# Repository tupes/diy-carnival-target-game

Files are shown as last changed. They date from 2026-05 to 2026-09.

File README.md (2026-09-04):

# DIY Electromechanical Carnival Target Game

> A one-off electromechanical arcade game independently engineered and fabricated as a gift—from embedded firmware and electronics to parametric CAD, 3D-printed mechanisms, and a full wooden cabinet.

<p align="center">
  <a href="docs/media/diy-carnival-target-gameplay.mp4">
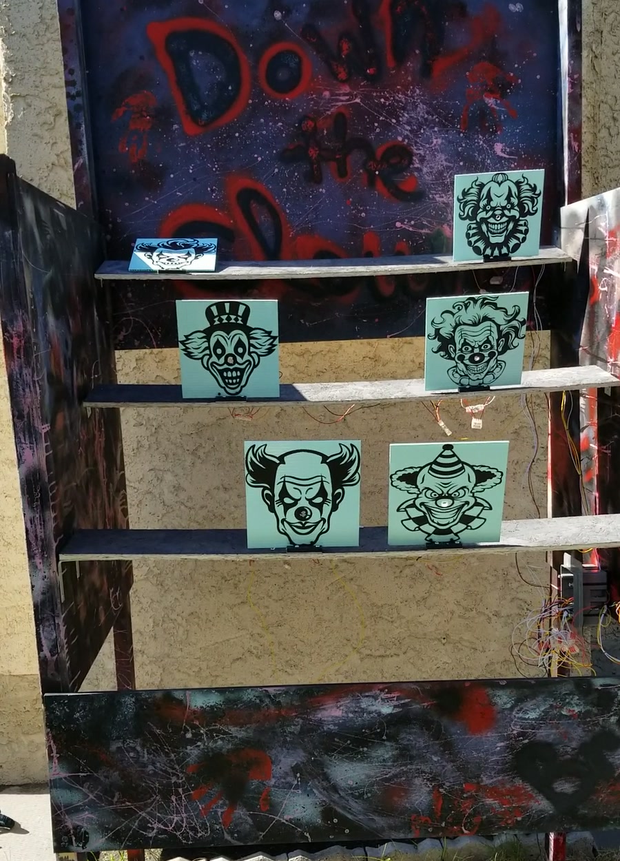
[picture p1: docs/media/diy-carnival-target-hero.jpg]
Completed wooden DIY electromechanical carnival target game
    
  </a>
</p>
<p align="center"><em>Completed integrated build during a live play session. Select the image to watch the full demonstration.</em></p>

The game turns a carnival ball toss into a 30-second embedded challenge. A player taps the M5Stack touchscreen to start, then throws balls at color-coded hinged clown targets. Each hit is detected by an ESP32, scored according to the target's current difficulty, acknowledged with sound and an updated display, and followed by an automatic servo-driven reset.

This project is an end-to-end build: interaction design, game logic, wireless communication, sensor and actuator integration, parametric mechanical design, fabrication, cabinet construction, system debugging, and delivery of a finished physical product.

The direct inspiration was [ICE's *Down the Clown* arcade game](https://www.icegame.com/games/down-the-clown/), which I enjoy playing. I recreated the experience as a non-commercial learning project, designing and implementing the firmware, electronics, mechanisms, CAD, fabrication workflow, and cabinet independently.

> [!IMPORTANT]
> This independent fan project is not affiliated with or endorsed by Innovative Concepts in Entertainment, Inc. No ICE software, artwork, audio, mechanical drawings, or fabrication files are included. Historical media shows the original working title used on the completed gift; that name is referenced here only to identify the inspiration.

## Engineering scope

| Area | Work delivered |
| --- | --- |
| Embedded systems | Wrote MicroPython firmware for an ESP32 target controller and an M5Stack touchscreen interface |
| Electronics | Integrated active-low hit switches, PWM-controlled servos, clocked addressable RGB lights, and embedded audio |
| Communication | Split real-time responsibilities across two controllers using routerless ESP-NOW broadcasts |
| Mechanical design | Created parametric servo cams, brackets, switch mounts, hinge stops, and a cabinet layout in Python |
| Fabrication | Produced vendor-neutral STEP exports and slicer-ready 3MF files, iterated on fit and geometry, and built the wooden cabinet |
| Integration and delivery | Brought firmware, wiring, printed parts, moving targets, UI, and enclosure together as a playable gift |

## Gameplay demonstration

<p align="center">
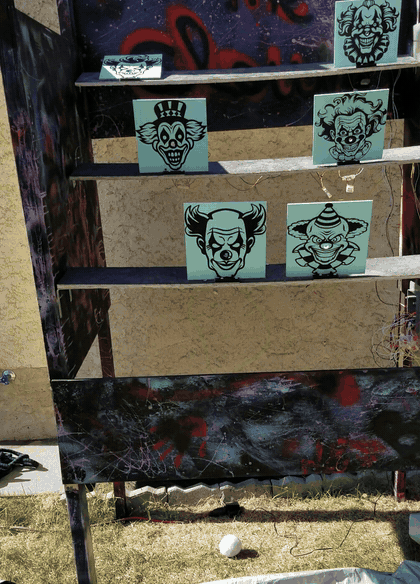
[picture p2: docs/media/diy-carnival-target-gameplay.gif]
A ball knocks down a clown target before the servo and cam automatically raise it
  
</p>

*A successful hit followed by the two-second cooldown and servo/cam reset.*

- [Watch the optimized 39-second gameplay demonstration (MP4)](docs/media/diy-carnival-target-gameplay.mp4)
- [View the M5Stack start interface](docs/media/diy-carnival-target-interface.jpg)

## System architecture

```mermaid
flowchart LR
    Player((Player))
    M5["M5Stack touchscreen<br/>UI · timer · score · audio"]
    ESP["ESP32 target controller<br/>state · GPIO · PWM · RGB buffer"]
    Targets["Hinged clown targets"]
    Switches["Active-low hit switches"]
    Servos["SG90 servos<br/>+ printed cam lobes"]
    Lights["Clocked addressable<br/>RGB lights"]

    Player -->|tap to start| M5
    Player -->|throw balls| Targets
    M5 -->|ESP-NOW: START / GAME OVER| ESP
    Targets -->|mechanical trip| Switches
    Switches -->|falling-edge GPIO interrupt| ESP
    ESP -->|target ID + points over ESP-NOW| M5
    ESP -->|50 Hz PWM| Servos
    Servos -->|raise target| Targets
    ESP -->|SoftSPI color frame| Lights
    M5 -->|countdown · score · sound| Player
```

The two-controller design keeps the player interface separate from the physical target loop:

- The **M5Stack** owns touch input, the 30-second timer, score and session high score, LCD rendering, and hit audio.
- The **ESP32** owns target state, switch interrupts, randomized point values, RGB cues, servo actuation, and reset timing.
- **ESP-NOW** carries `START` and `GAME OVER` commands to the target controller and returns compact `<target_id>-<points>` hit events to the display.

## How a round works

1. The player taps the M5Stack display. It creates a new game, draws the score and timer, registers its receive callback, and broadcasts `START`.
2. The ESP32 initializes five active target stations. Each target receives a weighted difficulty and an RGB point cue: green for 1 point, yellow for 2, or red for 3.
3. A falling-edge GPIO interrupt records a hit. The interrupt handler only latches state; the main loop performs the ESP-NOW send so radio work stays out of interrupt context.
4. The M5Stack parses the target ID and point value, updates the score, and plays a non-blocking sound effect.
5. After two seconds, the ESP32 runs the target's SG90 servo and custom cam to stand it back up. Upright targets can reroll their difficulty every five seconds.
6. When the timer reaches zero, the M5Stack shows the result and broadcasts `GAME OVER`; the ESP32 detaches the hit interrupts, turns off the target lights, resets the mechanisms, and returns to its waiting state.

## Hardware

| Subsystem | Components | Role |
| --- | --- | --- |
| Player interface | Touchscreen- and speaker-equipped M5Stack | Start input, countdown, score, high score, and audio feedback |
| Target controller | ESP32 | Game state, ESP-NOW messaging, GPIO sensing, servo PWM, and RGB output |
| Hit detection | Active-low switches with internal pull-ups | Detect a target falling through GPIO interrupts |
| Target reset | SG90 micro servos, custom cam lobes, and printed mounts | Convert servo rotation into a compact automatic lifting motion |
| Lighting | Clocked addressable RGB lights | Communicate each target's current point value |
| Structure | Hinged clown targets, three rising shelves, and a wooden cabinet | Form the physical playfield and protect the integrated system |

The current firmware enables **five targets**. The pin map and cabinet study retain a sixth mapped position, preserving an earlier layout option while only the configured stations are instantiated at runtime.

## Software and control design

### ESP32 target firmware

[`firmware/esp32/main.py`](firmware/esp32/main.py) implements a `WAITING` / `PLAYING` state machine and a reusable `Clown` abstraction. A declarative hardware map binds each station to its switch GPIO, servo GPIO, and LED index, making the control logic scale without duplicating per-target code.

Key behaviors include:

- routerless ESP-NOW setup and broadcast messaging;
- interrupt-driven hit capture with deferred message transmission;
- weighted difficulty selection by target position;
- a strip-wide RGB framebuffer sent over `SoftSPI`;
- calibrated 50 Hz servo PWM, reset dwell, and target cooldown timing; and
- explicit interrupt cleanup between rounds.

[`firmware/esp32/debug/lights.py`](firmware/esp32/debug/lights.py) reduces the lighting system to a one-pixel color test for isolated bench debugging.

### M5Stack interface firmware

[`firmware/m5stack/main.py`](firmware/m5stack/main.py) uses the M5Stack UIFlow MicroPython APIs to render the start, game, and game-over screens. It owns the round clock and score, receives hit events through an ESP-NOW callback, highlights the final ten seconds in red, and moves WAV playback to a background thread so audio does not stall the game loop.

### Development stack

- **Firmware:** MicroPython, M5Stack UIFlow APIs, ESP-NOW, GPIO interrupts, PWM, and `SoftSPI`
- **Parametric CAD:** Python, [`build123d`](https://build123d.readthedocs.io/), and `ocp_vscode`
- **Fabrication exchange:** STEP for vendor-neutral geometry exchange and 3MF for slicer-ready print projects
- **Setup and constraints:** [`firmware/README.md`](firmware/README.md) and [`hardware/models/README.md`](hardware/models/README.md)

The CAD compatibility baseline is pinned in [`requirements-cad.txt`](requirements-cad.txt), and model generators write to repository-relative export paths. The exact MicroPython/UIFlow builds remain unrecorded, and the M5Stack firmware expects `/flash/res/ding.wav`, which is not included. Hardware behavior should therefore be validated on both controllers before deployment.

## CAD and fabrication

### Cabinet layout

[`hardware/cabinet/arcade_cabinet.py`](hardware/cabinet/arcade_cabinet.py) is a full parametric layout study expressed in inches. It models:

- a 48-inch-wide, 36-inch-deep wooden structure with 2×4 legs;
- side and back panels, a sloped playfield, and three seven-inch shelves;
- target placement across the rising playfield;
- cable pass-through holes at the shelf edges;
- an ESP32 location near the middle row to reduce maximum wire length; and
- explicit under-shelf cable paths from each mechanism to the controller.

The cabinet script is a spatial integration model: it was used to reason about clearances, sightlines, component placement, and wiring before and during fabrication. Its numeric values are inches, so it intentionally remains visualization-only rather than emitting a STEP file that downstream tools would interpret as millimetres.

### Custom printed mechanisms

The parametric part generators in [`hardware/models/scripts/`](hardware/models/scripts/) are expressed in millimetres:

- [`cam_lobe.py`](hardware/models/scripts/cam_lobe.py) creates a teardrop SG90 cam with a fitted horn pocket and retaining-screw hole.
- [`servo_bracket.py`](hardware/models/scripts/servo_bracket.py) creates an L-shaped mount with servo-body clearance, machine-screw holes, and shelf-mounting holes.
- [`switch_bracket.py`](hardware/models/scripts/switch_bracket.py) combines a switch mount, wiring tunnel, and cabinet-mounting flanges.
- [`hinge_stop.py`](hardware/models/scripts/hinge_stop.py) creates a compact mechanical stop with configurable mounting geometry.

[`hardware/models/exports/`](hardware/models/exports/) contains both STEP and 3MF outputs. Multiple cam and hinge-stop variants preserve the physical iteration process: cam reach, horn-pocket clearance, hub geometry, pocket depth, and stop thickness were adjusted as the printed parts met real servos, hinges, targets, and cabinet tolerances.

### From bench prototype to cabinet

Before final installation, the target mechanisms were integrated on a cardboard bench fixture. This made the servo/cam motion, switch inputs, wiring distribution, ESP-NOW scoring, and M5Stack interface visible and accessible while the complete control loop was exercised across multiple stations.

| Bench integration prototype | Cabinet construction |
| :---: | :---: |
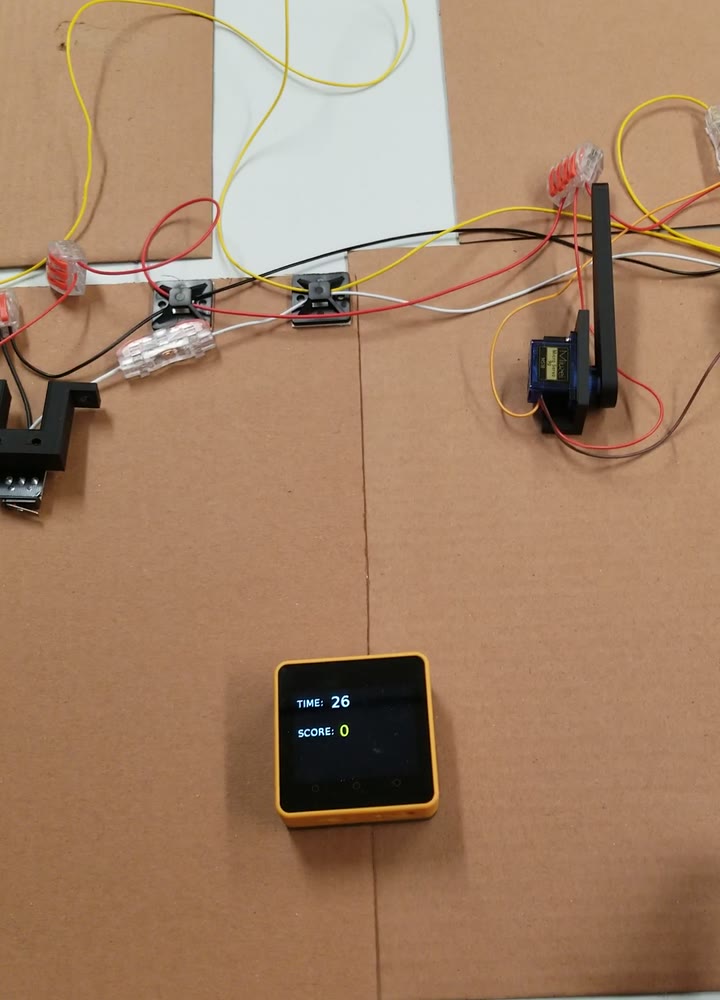
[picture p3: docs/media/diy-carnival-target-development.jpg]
Multiple wired servo and switch stations arranged around an M5Stack during bench integration
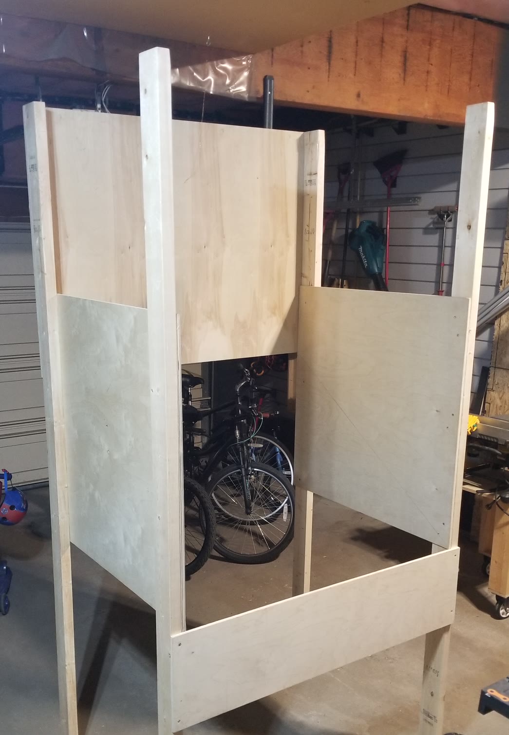
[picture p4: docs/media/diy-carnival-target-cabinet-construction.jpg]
Full-scale unpainted timber and plywood arcade cabinet during construction
|  |  |
| *Multi-station electromechanical integration before enclosure installation. [Watch the short bench test.](docs/media/diy-carnival-target-development.mp4)* | *Pre-paint cabinet assembly, showing the full-scale timber frame and plywood enclosure.* |

## Notable engineering and debugging challenges

### Rejecting transient hit signals

The target switches occasionally produced falling-edge callbacks that were no longer active by the time the handler ran. The hit handler now re-reads the GPIO and immediately rejects an event if the pin has already returned high. It also records only the minimum state needed in interrupt context and leaves ESP-NOW transmission to the main loop.

### Sharing timing-sensitive resources

The ESP32 services GPIO interrupts and ESP-NOW while also clocking complete RGB frames to the light string. LED writes are buffered, then sent inside a deliberately short interrupt-disabled section before interrupts are restored for radio and hit processing. A separate minimal light script made it possible to test clock, data, wiring, and color order without the rest of the game running.

### Turning servo motion into a reliable reset

An off-the-shelf SG90 did not directly solve the target-reset geometry. The reset system required a custom cam profile, horn pocket, retaining feature, bracket, and calibrated motion sequence. The exported variants show the practical loop of printing, fitting, measuring, changing parameters, and printing again.

### Designing the cabinet around the integration

The enclosure was not treated as a box added at the end. The CAD model includes the playfield slope, shelf heights, mechanism envelopes, controller location, wiring drops, and pass-throughs. That made electronics access and cable length part of the mechanical design rather than late-stage rework.

## Repository map

```text
.
├── LICENSE                      # MIT license for software and repository tooling
├── docs/media/                  # CC BY 4.0 build stills, GIF, and videos
│   ├── LICENSE                  # Complete CC BY 4.0 license text
│   └── NOTICE.md                # Media scope, attribution, and rights notice
├── firmware/
│   ├── README.md                # Deployment, protocol, pin map, and test boundaries
│   ├── esp32/
│   │   ├── main.py               # Target controller
│   │   └── debug/lights.py       # Isolated RGB bench test
│   └── m5stack/main.py           # Touch UI, timer, score, and audio
├── hardware/
│   ├── LICENSE                  # CERN-OHL-P-2.0 hardware license
│   ├── NOTICE.md                # Hardware scope, copyright, and source notice
│   ├── cabinet/arcade_cabinet.py # Parametric cabinet and wiring layout
│   └── models/
│       ├── README.md              # CAD environment and export manifest
│       ├── scripts/              # Parametric printed-part generators
│       └── exports/              # STEP and 3MF design outputs
├── pyproject.toml                # Ruff lint/format configuration
├── requirements-cad.txt          # Tested build123d compatibility baseline
└── requirements-dev.txt          # Repository validation tools
```

## Local validation

The desktop checks are intentionally static because the firmware depends on physical controllers and legacy device APIs:

```shell
python -m pip install -r requirements-dev.txt
ruff check .
ruff format --check firmware hardware
python -m compileall -q firmware hardware
```

The four printable CAD generators are additionally regression-checked against the bounds, volume, and topology of their checked-in canonical STEP files when the CAD dependencies are available. Device behavior, radio timing, switches, lights, audio, and calibrated servo travel still require the physical ESP32/M5Stack test rig.

## Licensing and third-party rights

| Material | License |
| --- | --- |
| Firmware and repository tooling | [MIT](LICENSE) |
| Original hardware design sources and fabrication exports under `hardware/` | [CERN-OHL-P-2.0](hardware/LICENSE) |
| Original photographs, videos, and derived media listed in `docs/media/NOTICE.md` | [CC BY 4.0](docs/media/LICENSE) |

These licenses cover only original contributions to this repository. They do not grant rights in third-party names, trademarks, artwork, or other intellectual property. Any rights associated with ICE or *Down the Clown* remain with their respective owners.

## Project status

The game was completed and delivered as a gift. This repository captures the independently developed firmware, cabinet layout, parametric part sources, and fabrication exports; it is a non-commercial project archive and engineering portfolio, not a commercial kit or step-by-step assembly guide.

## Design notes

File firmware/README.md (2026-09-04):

# Firmware notes

The game runs as two cooperating MicroPython programs. They target different device APIs and are deployed separately; neither file is intended to run under desktop CPython.

The public M5Stack source uses the neutral title **Carnival Targets**. Historical demonstration media shows the working title that appeared on the one-off gift; the gameplay and controller protocol are otherwise unchanged.

| Controller | Source | Responsibilities |
| --- | --- | --- |
| ESP32 | [`esp32/main.py`](esp32/main.py) | Target state, active-low switches, servo PWM, RGB output, difficulty selection, and hit transmission |
| Touchscreen M5Stack | [`m5stack/main.py`](m5stack/main.py) | Touch input, round timing, scoring, high score, LCD rendering, and hit audio |

## ESP-NOW protocol

All current messages are broadcasts:

| Direction | Payload | Meaning |
| --- | --- | --- |
| M5Stack → ESP32 | `START` | Create and enable the target stations for a new round |
| M5Stack → ESP32 | `GAME OVER` | Disable hit interrupts, clear the lights, and reset the mechanisms |
| ESP32 → M5Stack | `<target_id>-<points>` | Add 1–3 points for the specified zero-based target |

The protocol is intentionally small, but it is best-effort: it has no acknowledgement, session ID, or duplicate suppression. A production revision should add coordinated retry/acknowledgement semantics to both controllers and verify them on hardware; retrying hit messages alone would risk double-scoring.

The M5Stack wrapper is initialized with channel argument `0` and string data type `1`. The exact legacy UIFlow build used for the delivered game was not recorded, so radio-channel changes should be tested on both devices together.

## ESP32 pin map

The firmware currently enables the first five stations.

| Station | Status | Switch GPIO | Servo GPIO | LED index |
| ---: | --- | ---: | ---: | ---: |
| 1 | Active | 18 | 14 | 0 |
| 2 | Active | 23 | 27 | 1 |
| 3 | Active | 19 | 26 | 2 |
| 4 | Active | 22 | 25 | 3 |
| 5 | Active | 21 | 33 | 4 |
| 6 | Reserved layout | 37 | 32 | 5 |

The clocked RGB connection uses GPIO 13 for clock and GPIO 4 for data. The `SoftSPI` constructor also receives GPIO 12 as MISO, although the game does not consume return data from the lights.

The sixth switch mapping is historical. On a classic ESP32, GPIO 37 does not provide the internal pull-up used by the active stations; enabling it requires an external pull-up or a verified remap.

## Deployment requirements

### ESP32

- Install an ESP32 MicroPython build that includes `espnow`.
- Copy [`esp32/main.py`](esp32/main.py) to the board as `/main.py`.
- Use [`esp32/debug/lights.py`](esp32/debug/lights.py) as a temporary diagnostic script when isolating the clock/data/color path.

### M5Stack

- Use a touch-capable M5Stack firmware with the legacy UIFlow 1-style `m5stack`, `uiflow`, and `libs.m5_espnow` APIs.
- Deploy [`m5stack/main.py`](m5stack/main.py) through the matching UIFlow/MicroPython workflow.
- Copy a compatible score sound to `/flash/res/ding.wav`, or leave audio unavailable; the sound file is not included in this repository.

## Hardware-validation boundaries

- `SERVO_UP_DUTY` and `SERVO_DOWN_DUTY` are calibrated legacy PWM duty values, not angles. Do not translate them to `duty_u16` or `duty_ns` without rechecking the mechanism travel.
- Servo movement deliberately blocks for 0.5 seconds. Replacing it with a non-blocking actuator state machine would improve radio responsiveness but changes mechanical timing.
- Round teardown leaves servo PWM active so the delivered mechanism retains its calibrated resting behavior. Test target stability and power draw on the physical assembly before adding `PWM.deinit()`.
- `START` and `GAME OVER` are each sent once. Reliability improvements require a coordinated protocol change across both devices.
- The exact MicroPython, M5Stack hardware, and UIFlow versions used for delivery were not archived, so all flash/runtime changes require a two-controller bench test.

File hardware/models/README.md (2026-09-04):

# Parametric models and fabrication exports

The printable mechanisms are authored in millimetres with build123d algebra-mode scripts. Canonical STEP outputs and the slicer-ready 3MF projects used during development are checked in so the design can be inspected without recreating the original CAD environment.

## Environment

- Python 3.10 or newer
- Dependencies from [`requirements-cad.txt`](../../requirements-cad.txt)
- Optional: `ocp-vscode` for interactive previews

```shell
python -m pip install -r requirements-cad.txt
# Optional interactive viewer:
python -m pip install ocp-vscode
```

The compatibility baseline is build123d 0.10.0. The scripts make preview support optional, so STEP export works without a running VS Code viewer.

## Generators

Run scripts from any working directory; each one writes its canonical STEP file to [`exports/`](exports/).

| Script | Canonical STEP output | Default overall bounds |
| --- | --- | --- |
| [`scripts/cam_lobe.py`](scripts/cam_lobe.py) | `arcade_cam_lobe_80-3.6-4.0-4.0.step` | 93 × 18 × 6 mm |
| [`scripts/servo_bracket.py`](scripts/servo_bracket.py) | `clown_servo_bracket.step` | 44 × 16 × 24 mm |
| [`scripts/hinge_stop.py`](scripts/hinge_stop.py) | `hinge_stop-16-8.step` | 64 × 17 × 8 mm |
| [`scripts/switch_bracket.py`](scripts/switch_bracket.py) | `switch_tunnel_bracket.step` | 54 × 12 × 35 mm |

Example:

```shell
python hardware/models/scripts/cam_lobe.py
```

Review the resulting STEP diff before replacing a fabrication file. The scripts intentionally expose their dimensions near the top for physical iteration.

## Export history

The additional cam and hinge-stop filenames preserve design iterations rather than a formal release sequence. The repository does not record which exact variant was installed in the delivered cabinet, so those files should not be deleted or renamed based only on their timestamps.

The 3MF files are Bambu Studio 2.3.2 projects created around an X1 Carbon with a 0.4 mm nozzle. They contain a mix of 0.20 mm Precision and 0.28 mm Extra Draft profiles. Treat those settings as historical starting points and select material, orientation, supports, tolerances, and a printer profile appropriate to the machine actually producing the part.

## Cabinet model

[`../cabinet/arcade_cabinet.py`](../cabinet/arcade_cabinet.py) is a spatial layout study whose numeric values are inches. build123d's default geometry/export convention is millimetres, so the script intentionally does **not** export a manufacturing STEP: an unscaled export would declare those inch-valued numbers as millimetres and open 25.4× too small.

The cabinet study retains six target positions while the delivered firmware enables five. It also preserves the original 96-inch raw floor-board study and back-panel placement; change those dimensions only against physical measurements of the build.

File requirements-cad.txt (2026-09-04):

# Compatibility baseline for the parametric CAD sources.
build123d==0.10.0

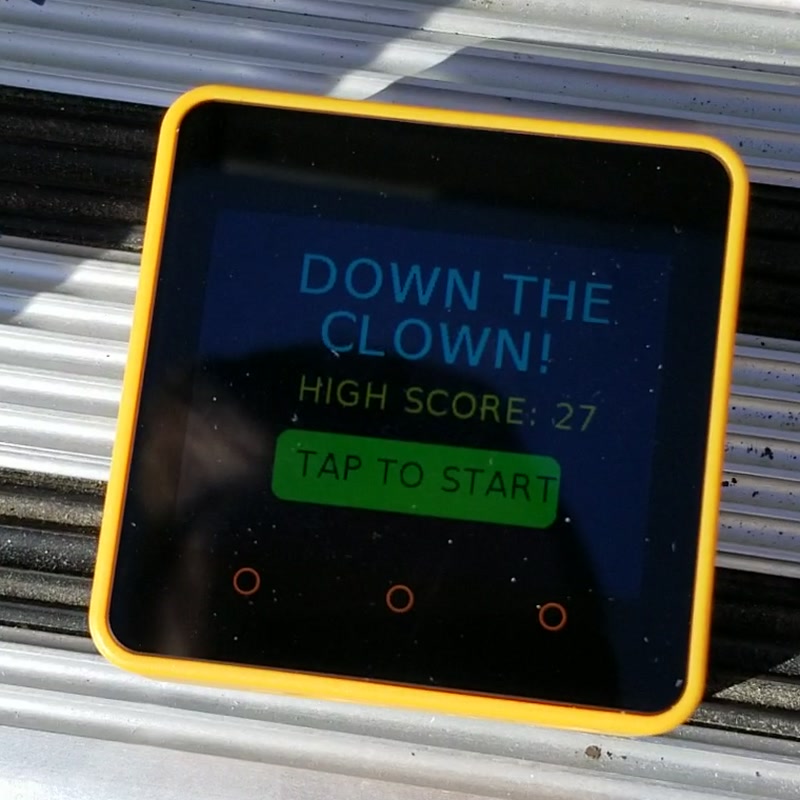
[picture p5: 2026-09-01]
docs/media/diy-carnival-target-interface.jpg

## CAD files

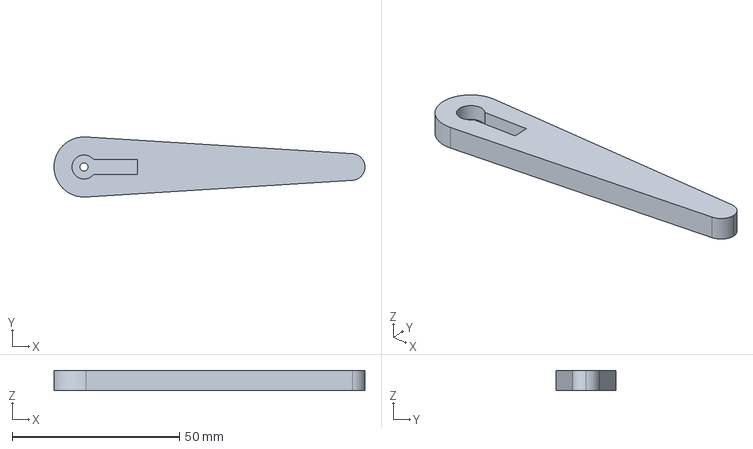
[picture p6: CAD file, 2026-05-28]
hardware/models/exports/arcade_cam_lobe_80-3.6-4.0-4.0.step
93.0 x 18.0 x 6.00 mm

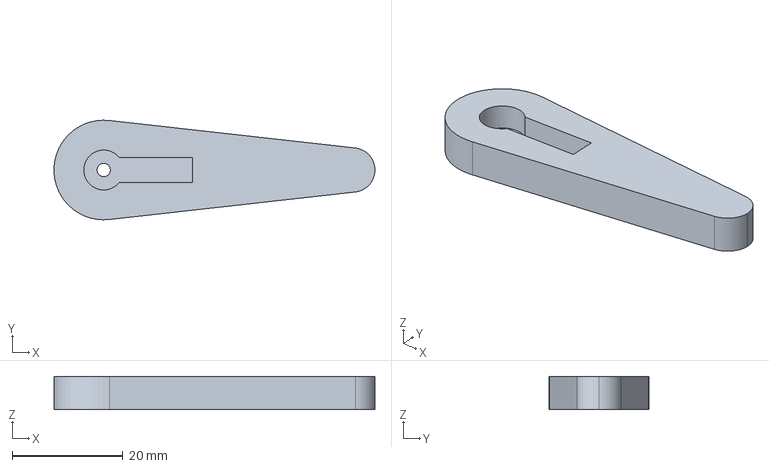
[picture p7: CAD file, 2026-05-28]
hardware/models/exports/arcade_cam_lobe_3.6-4.0-4.0.step
58.0 x 18.0 x 6.00 mm

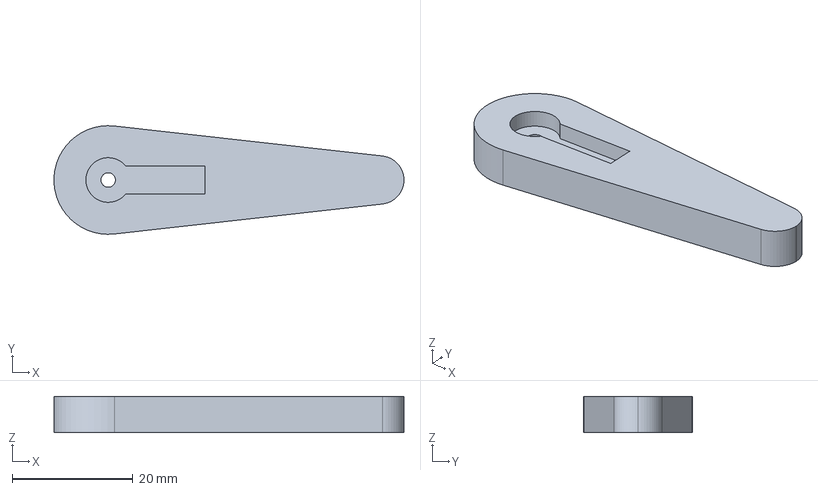
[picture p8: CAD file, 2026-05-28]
hardware/models/exports/arcade_cam_lobe_v2_3.7.step
58.0 x 18.0 x 6.00 mm

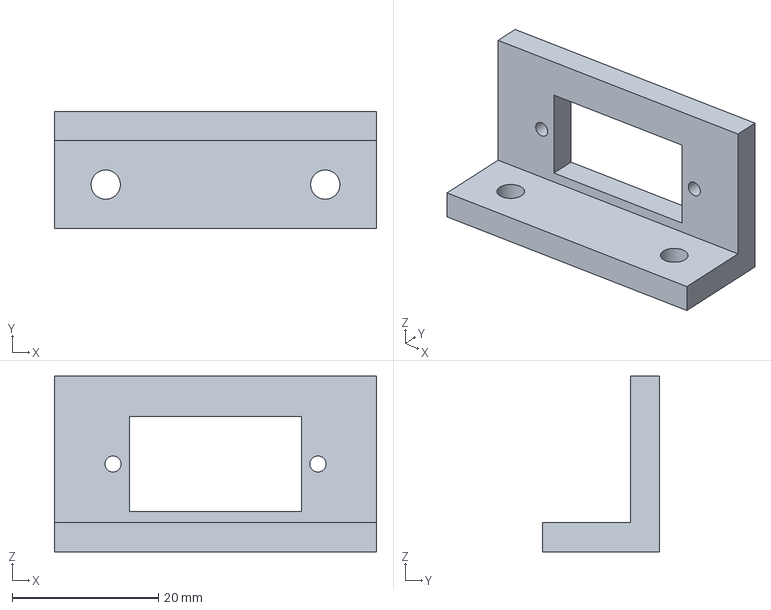
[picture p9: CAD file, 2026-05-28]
hardware/models/exports/clown_servo_bracket.step
44.0 x 16.0 x 24.0 mm

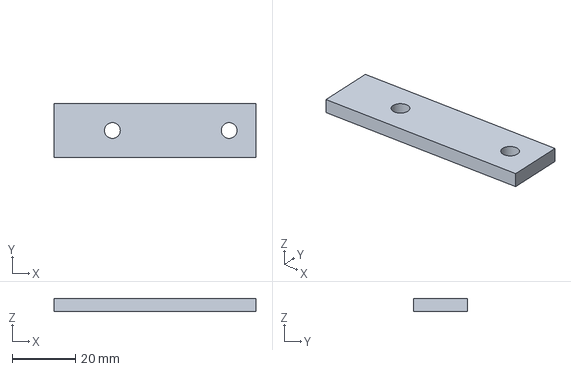
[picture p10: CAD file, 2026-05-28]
hardware/models/exports/hinge_stop-16-4.step
64.0 x 17.0 x 4.00 mm

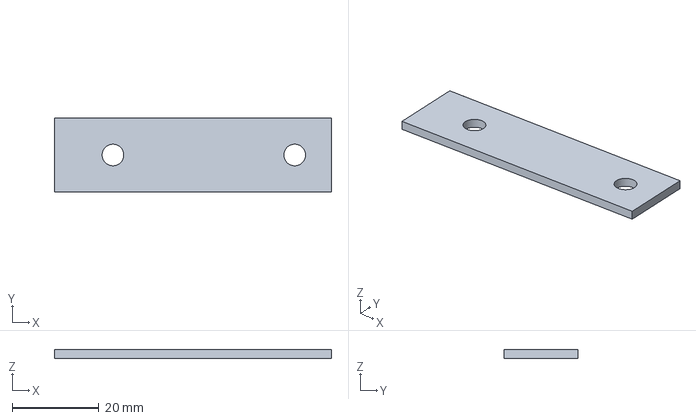
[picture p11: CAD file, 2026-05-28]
hardware/models/exports/hinge_stop-16.step
64.0 x 17.0 x 2.00 mm

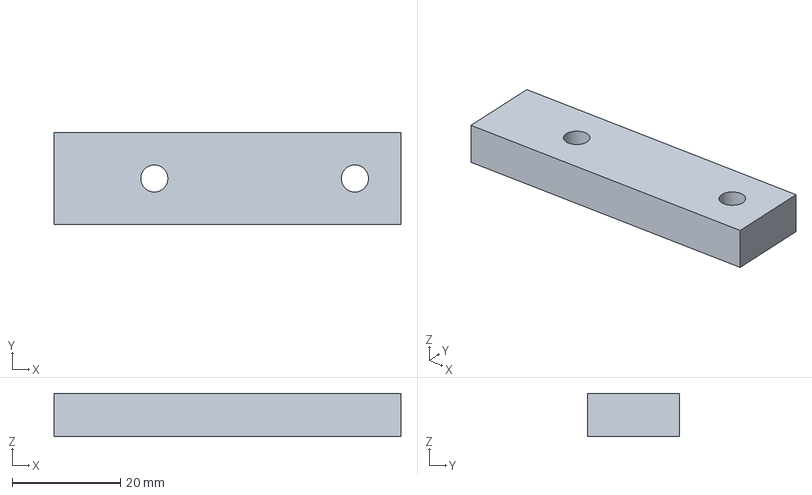
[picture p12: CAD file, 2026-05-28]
hardware/models/exports/hinge_stop-16-8.step
64.0 x 17.0 x 8.00 mm

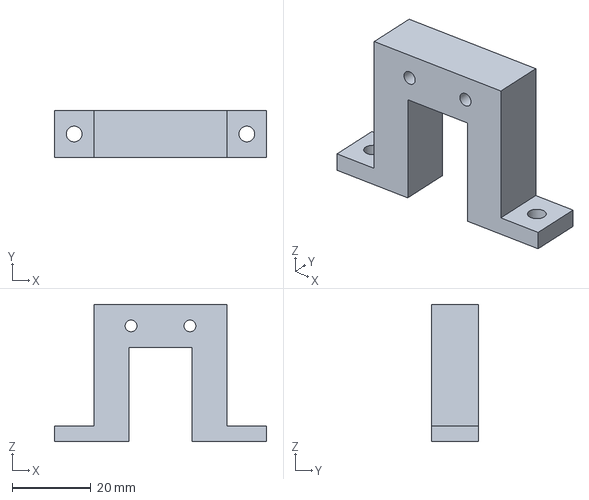
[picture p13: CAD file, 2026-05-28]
hardware/models/exports/switch_tunnel_bracket.step
54.0 x 12.0 x 35.0 mm

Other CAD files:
hardware/models/exports/arcade_cam_lobe_3.6-4.0-2.5.step
hardware/models/exports/hinge_stop.step
hardware/models/exports/arcade_cam_lobe_v2.step
hardware/models/exports/arcade_cam_lobe_3.6-4.0-2.5.3mf
hardware/models/exports/arcade_cam_lobe_3.6-4.0-4.0.3mf
hardware/models/exports/arcade_cam_lobe_80-3.6-4.0-4.0.3mf
hardware/models/exports/arcade_cam_lobe_v2.3mf
hardware/models/exports/arcade_cam_lobe_v2_3.7.3mf
hardware/models/exports/clown_servo_bracket.3mf
hardware/models/exports/hinge_stop-16-4.3mf
hardware/models/exports/hinge_stop-16-8.3mf
hardware/models/exports/hinge_stop.3mf
hardware/models/exports/switch_tunnel_bracket.3mf

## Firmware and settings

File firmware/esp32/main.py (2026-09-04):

# SPDX-FileCopyrightText: 2026 Mark Tupala
# SPDX-License-Identifier: MIT

"""ESP32 target controller for the DIY carnival target game."""

import espnow
import machine
import network
import random
import time
from machine import Pin, PWM, SoftSPI

# SERVO CONSTANTS
SERVO_DOWN_DUTY = 40
SERVO_UP_DUTY = 115
SERVO_FREQUENCY = 50
SERVO_WAIT_DURATION = 0.5  # seconds

# NETWORK CONSTANTS
BROADCAST_MAC = b"\xff\xff\xff\xff\xff\xff"
RECEIVE_TIMEOUT_MS = 100
START_COMMAND = b"START"
GAME_OVER_COMMAND = b"GAME OVER"

# CLOWN CONSTANTS
NUM_CLOWNS = 5

# LIGHT CONSTANTS
SPI_CLOCK_PIN = 13
SPI_DATA_PIN = 4
SPI_UNUSED_MISO_PIN = 12
SPI_BAUDRATE = 100_000
LIGHT_SPACING = 1
GREEN = (0, 255, 0)
YELLOW = (255, 255, 0)
RED = (255, 0, 0)
OFF = (0, 0, 0)

HARDWARE_MAP = [
    {"switch": 18, "servo": 14, "light": 0 * LIGHT_SPACING},
    {"switch": 23, "servo": 27, "light": 1 * LIGHT_SPACING},
    {"switch": 19, "servo": 26, "light": 2 * LIGHT_SPACING},
    {"switch": 22, "servo": 25, "light": 3 * LIGHT_SPACING},
    {"switch": 21, "servo": 33, "light": 4 * LIGHT_SPACING},
    {"switch": 37, "servo": 32, "light": 5 * LIGHT_SPACING},
]

if not 0 < NUM_CLOWNS <= len(HARDWARE_MAP):
    raise ValueError("NUM_CLOWNS must select at least one configured target")

NUM_TOTAL_LEDS = max(hardware["light"] for hardware in HARDWARE_MAP[:NUM_CLOWNS]) + 1
led_buffer = bytearray(NUM_TOTAL_LEDS * 3)

EASY, MEDIUM, HARD = "easy", "medium", "hard"
DIFFICULTY_VALUES = {
    EASY: {"points": 1, "color": GREEN},
    MEDIUM: {"points": 2, "color": YELLOW},
    HARD: {"points": 3, "color": RED},
}

# GAME CONSTANTS
CLOWN_RESET_DURATION = 2000  # ms
CLOWN_REROLL_DURATION = 5000  # ms
GAME_LOOP_DURATION = 0.05  # seconds

# GAME STATES
WAITING = "waiting"
PLAYING = "playing"


class Clown:
    def __init__(self, clown_id):
        self.id = clown_id
        self.switch = None
        self.servo = None

        try:
            hardware = HARDWARE_MAP[self.id]
            self.switch = Pin(hardware["switch"], Pin.IN, Pin.PULL_UP)
            self.servo = PWM(Pin(hardware["servo"]), freq=SERVO_FREQUENCY)
            self.light_id = hardware["light"]

            self.is_down = False
            self.needs_broadcast = False
            self.time_hit = 0

            random_age = random.randint(0, CLOWN_REROLL_DURATION // 2)
            self.last_roll_time = time.ticks_add(time.ticks_ms(), -random_age)

            self.apply_new_difficulty()
            self.stand_up()
            self.turn_light_on()

            self.switch.irq(trigger=Pin.IRQ_FALLING, handler=self.hit)
        except Exception:
            self._release_failed_initialization()
            raise

    def _release_failed_initialization(self):
        """Release hardware owned by a target that could not finish setup."""
        if self.switch is not None:
            try:
                self.switch.irq(handler=None)
            except Exception:
                pass

        if self.servo is not None:
            try:
                self.servo.deinit()
            except Exception:
                pass

    def apply_new_difficulty(self):
        """Calculates new stats and updates the point/color values."""
        self.difficulty = roll_difficulty(self.id)
        self.points = DIFFICULTY_VALUES[self.difficulty]["points"]
        self.color = DIFFICULTY_VALUES[self.difficulty]["color"]

    def set_arm_down(self):
        self.servo.duty(SERVO_DOWN_DUTY)

    def set_arm_up(self):
        self.servo.duty(SERVO_UP_DUTY)

    def stand_up(self):
        print(f"Standing up Clown {self.id}")
        self.set_arm_up()
        time.sleep(SERVO_WAIT_DURATION)
        self.set_arm_down()  # Hide the arm away from the impact zone.

    def turn_light_on(self):
        set_single_light(self.light_id, self.color)

    def turn_light_off(self):
        set_single_light(self.light_id, OFF)

    def hit(self, pin):
        # Keep the IRQ callback allocation-free and defer I/O to the main loop.
        if pin.value() == 1 or self.is_down:
            return

        self.time_hit = time.ticks_ms()
        self.needs_broadcast = True
        self.is_down = True

    def reset(self):
        self.apply_new_difficulty()
        self.stand_up()
        self.turn_light_on()

        self.time_hit = 0
        self.last_roll_time = time.ticks_ms()
        self.needs_broadcast = False
        self.is_down = False

    def destroy(self):
        print(f"Destroying Clown {self.id}")

        self.needs_broadcast = False
        self.is_down = True
        cleanup_error = None

        # Attempt every cleanup step even if one hardware operation fails.
        try:
            self.switch.irq(handler=None)
        except Exception as error:
            cleanup_error = error

        try:
            self.turn_light_off()
        except Exception as error:
            if cleanup_error is None:
                cleanup_error = error

        try:
            self.stand_up()
        except Exception as error:
            if cleanup_error is None:
                cleanup_error = error

        if cleanup_error is not None:
            raise cleanup_error


def create_network_connection():
    # Turn on the WiFi antenna, but disconnect from any routers
    wlan = network.WLAN(network.STA_IF)
    wlan.active(True)
    wlan.disconnect()

    # Turn on the ESP-NOW protocol
    connection = espnow.ESPNow()
    connection.active(True)

    connection.add_peer(BROADCAST_MAC)
    print("Network connection ready! Listening for commands...")
    return wlan, connection


def close_network_connection(wlan, connection):
    """Best-effort radio cleanup after an exception or manual interruption."""
    try:
        connection.active(False)
    except Exception as error:
        print("Unable to deactivate ESP-NOW during shutdown:", error)

    try:
        wlan.disconnect()
        wlan.active(False)
    except Exception as error:
        print("Unable to deactivate Wi-Fi during shutdown:", error)


def push_led_data():
    """Sends the current state of the led_buffer to the physical strip."""
    state = machine.disable_irq()
    try:
        spi.write(led_buffer)
    finally:
        machine.enable_irq(state)

    time.sleep_ms(10)


def set_single_light(light_index, color):
    """Updates a specific LED in the buffer and pushes the change."""
    if not 0 <= light_index < NUM_TOTAL_LEDS:
        raise ValueError("light index is outside the LED buffer")

    start_idx = light_index * 3
    led_buffer[start_idx] = color[0]
    led_buffer[start_idx + 1] = color[1]
    led_buffer[start_idx + 2] = color[2]
    push_led_data()


def initialize_lights():
    for i in range(len(led_buffer)):
        led_buffer[i] = 0

    push_led_data()


spi = SoftSPI(
    baudrate=SPI_BAUDRATE,
    polarity=0,
    phase=0,
    sck=Pin(SPI_CLOCK_PIN),
    mosi=Pin(SPI_DATA_PIN),
    miso=Pin(SPI_UNUSED_MISO_PIN),
)
initialize_lights()


def roll_difficulty(clown_id):
    """Return a weighted difficulty based on target position."""
    roll = random.randint(1, 100)
    if clown_id < 2:  # Clowns 1 and 2
        if roll <= 75:
            return EASY
        return MEDIUM

    if clown_id < 4:  # Clowns 3 and 4
        if roll <= 25:
            return EASY
        if roll <= 75:
            return MEDIUM
        return HARD

    if clown_id < 6:  # Clowns 5 and 6
        if roll <= 25:
            return MEDIUM
        return HARD

    raise ValueError("clown id is outside the configured difficulty map")


def destroy_clowns(active_clowns):
    """Best-effort shutdown for every initialized target station."""
    for clown in active_clowns:
        try:
            clown.destroy()
        except Exception as error:
            print("Error while shutting down Clown", clown.id, error)


def create_clowns():
    """Construct a complete round, cleaning up if initialization is partial."""
    new_clowns = []
    try:
        for clown_id in range(NUM_CLOWNS):
            new_clowns.append(Clown(clown_id))
            time.sleep_ms(300)
    except Exception:
        destroy_clowns(new_clowns)
        raise

    return new_clowns


def run_controller(connection):
    """Run the target-controller state machine until reset or failure."""
    clowns = []
    state = WAITING

    print("Device initialized and awaiting START command")

    try:
        while True:
            _host, command = connection.recv(timeout_ms=RECEIVE_TIMEOUT_MS)

            if command is not None:
                print("Received command:", command)

            if state == WAITING:
                if command == START_COMMAND:
                    print("Starting new game")
                    clowns = create_clowns()
                    state = PLAYING
                elif command is not None:
                    print("Ignoring command while waiting:", command)

            elif state == PLAYING:
                if command == GAME_OVER_COMMAND:
                    print("Ending game")
                    destroy_clowns(clowns)
                    clowns = []
                    state = WAITING
                    continue
                if command is not None:
                    print("Ignoring command while playing:", command)

                current_time = time.ticks_ms()
                for clown in clowns:
                    if clown.is_down:
                        if clown.needs_broadcast:
                            hit_message = "%d-%d" % (clown.id, clown.points)
                            connection.send(BROADCAST_MAC, hit_message.encode("utf-8"))
                            clown.needs_broadcast = False
                        if (
                            time.ticks_diff(current_time, clown.time_hit)
                            >= CLOWN_RESET_DURATION
                        ):
                            clown.reset()
                    elif (
                        time.ticks_diff(current_time, clown.last_roll_time)
                        >= CLOWN_REROLL_DURATION
                    ):
                        clown.apply_new_difficulty()
                        clown.turn_light_on()
                        clown.last_roll_time = current_time

            time.sleep(GAME_LOOP_DURATION)
    finally:
        destroy_clowns(clowns)
        try:
            initialize_lights()
        except Exception as error:
            print("Unable to clear target lights during shutdown:", error)


def main():
    wlan, connection = create_network_connection()
    try:
        run_controller(connection)
    finally:
        close_network_connection(wlan, connection)


main()

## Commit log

2026-05-28 Added main.py for ESP32 backend
2026-05-28 Added script for generating switch bracket
2026-05-28 Added script for generating servo bracket
2026-05-28 Added script for generating hinge stop
2026-05-28 Added script for generating servo cam
2026-05-28 Committing a bunch of STEP and 3MF files for printed parts
    [arcade_cam_lobe_3.6-4.0-2.5.3mf, arcade_cam_lobe_3.6-4.0-2.5.step, arcade_cam_lobe_3.6-4.0-4.0.3mf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]
2026-05-28 Added script for debugging lights on ESP32
2026-05-28 Fixed false trigger of switches by checking pin value
    [main.py]
